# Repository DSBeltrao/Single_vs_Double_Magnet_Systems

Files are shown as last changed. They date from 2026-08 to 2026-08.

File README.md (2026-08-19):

This repository supports the paper "Actuation Comparison of Microrobots Using Single and Double Permanent Magnets." It contains all files needed to reproduce the simulations, the experimental setup, calculations and 3D prints.

Repository Structure

1. **Simulations** – Source files for simulating the magnetic field generation, gradient velocity and navigation control.
2. **Experimental Setup** – Wiring diagram, manuals for the electronic components, Arduino codes, Python codes, list of setup parts and overview of control procedure.
3. **Experimental Calculations** - Python codes for extracting and processing data.
4. **3D Prints** - Files containing the 3D prints used for the system setup in the formats 3mf and f3d.

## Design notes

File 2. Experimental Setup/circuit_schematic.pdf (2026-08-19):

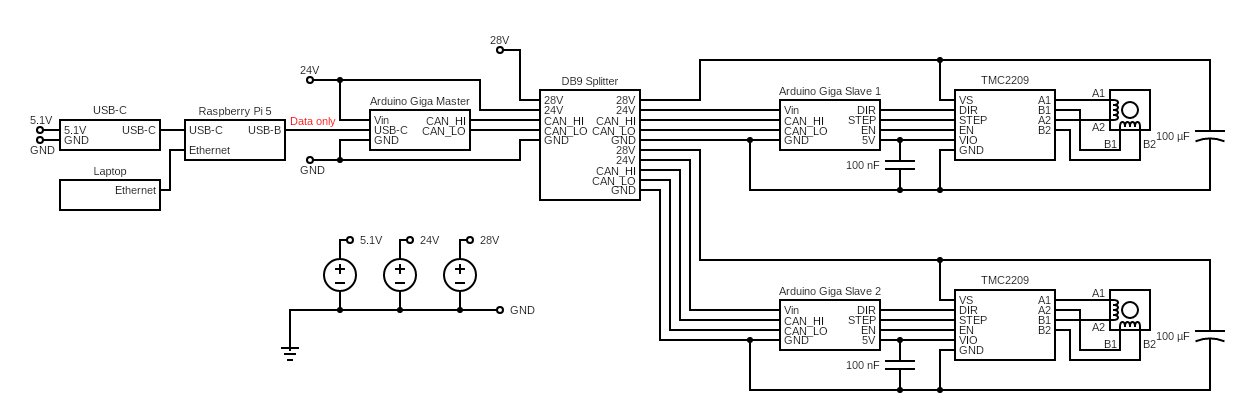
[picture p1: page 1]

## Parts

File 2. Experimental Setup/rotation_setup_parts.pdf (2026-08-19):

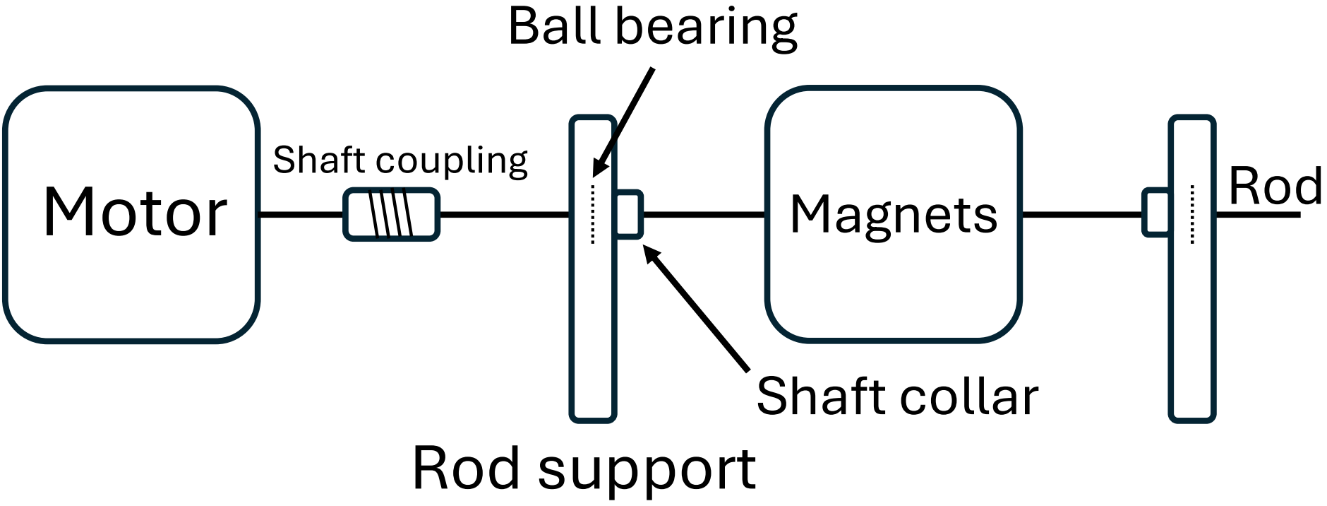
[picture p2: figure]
Motor; Shaft coupling; Rod support; Shaft collar; Magnets; Ball bearing; Rod

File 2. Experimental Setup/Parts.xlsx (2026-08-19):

Component | Quantity
Structure
Aluminium profile 8 500x40x40 mm | 14
Aluminium profile 8 500x80x40 mm | 4
Cube fastening 3D profile 8 | 8
Automatic fastening screws profile 8 | 24
Acryllic plates
Acryllic protection plate 520x520x2 mm | 5
Acryllic pool support plate 500x580x4 mm | 1
Acryllic pool plate stroke 500x20x4 mm | 2
Electonics
NEMA 17 stepper motor | 2
TMC2209 stepper driver | 2
Arduino GIGA R1 | 3
Arduino GIGA CAN hat | 2
Raspberry Pi 5 8GB and accesoires (SD card, power, casing, etc.) | 1
DB9 cable | 2
DB9 splitter | 1
100uF capacitor | 2
100nF capacitor | 2
EDU36311A Triple Output Programmable Power Supply | 1
USB-B to USB-C data only cable | 1
USB-C open end cable | 1
Ethernet cable | 1
3D prints and accessories
Magnet holder | 2
Rod support | 2
Arduino mount | 2
Acryllic plate holder | 10
Motor mount | 2
Pool | 1
Profile 8 M4 15 mm screw and nut | 20
M3 6 mm screw | 8
M3 10 mm screw | 16
M2 20 mm grub screw | 8
Steel rod 5mm diameter 250 mm length | 2
Shaft collar 5 mm | 4
Ball bearing 5x16x5 mm | 4
Hot melt insert M2 | 8
Hot melt insert M3 | 16
M3 nut | 8
Flexible shaft coupling 5mm-5mm | 2
Magnet 40x40x20 N42 | 4
Microrobot | 1
Glycerin
15x15 cm printed grid | 1

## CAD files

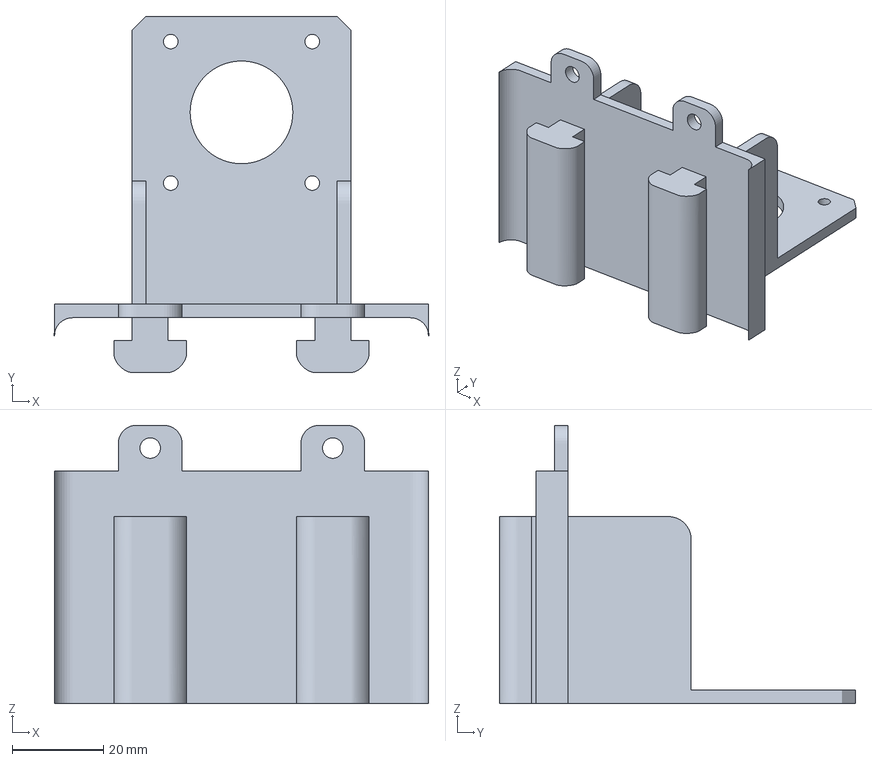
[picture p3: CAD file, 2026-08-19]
4. 3D Prints/3mf_files/motorMount.3mf
82.0 x 78.0 x 61.0 mm

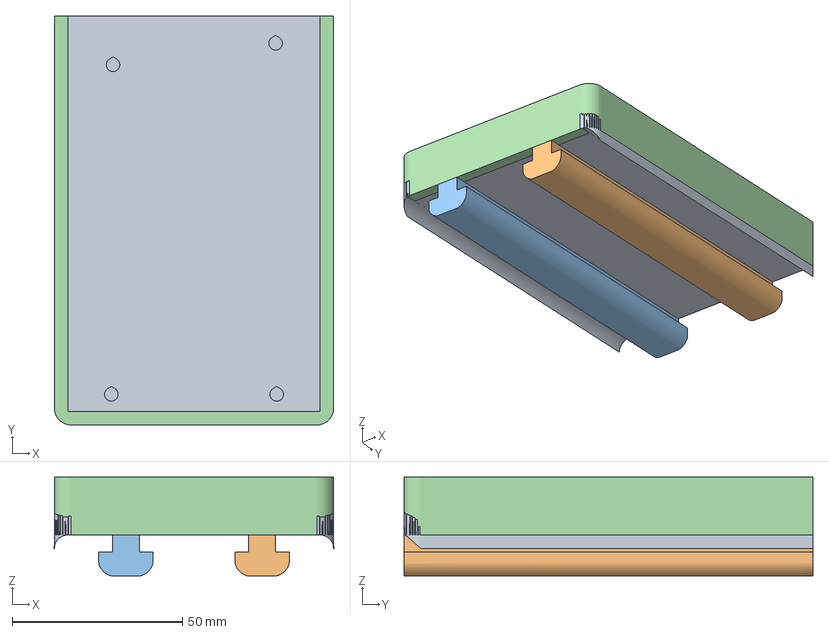
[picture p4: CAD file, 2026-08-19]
4. 3D Prints/3mf_files/arduinoMount.3mf
82.0 x 120.0 x 29.0 mm

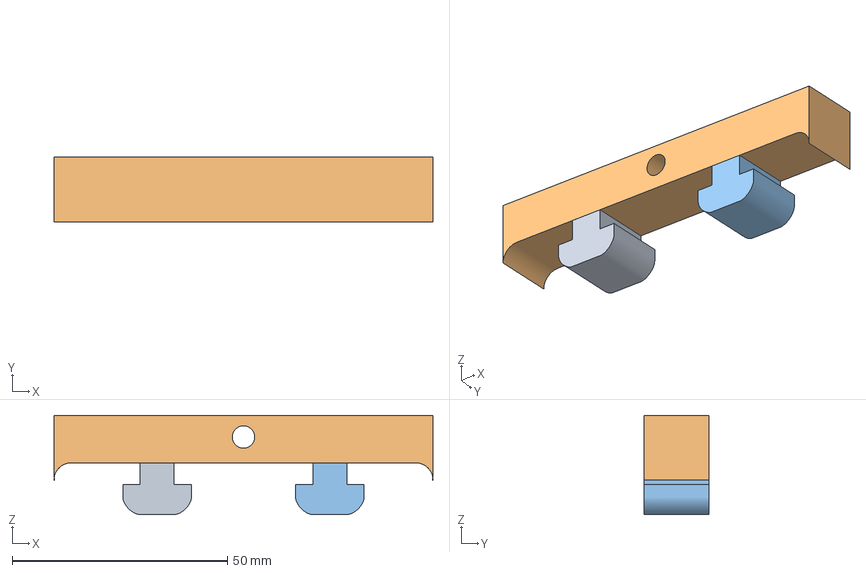
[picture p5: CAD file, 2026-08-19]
4. 3D Prints/3mf_files/dimensionsTest.3mf
88.0 x 15.0 x 23.0 mm

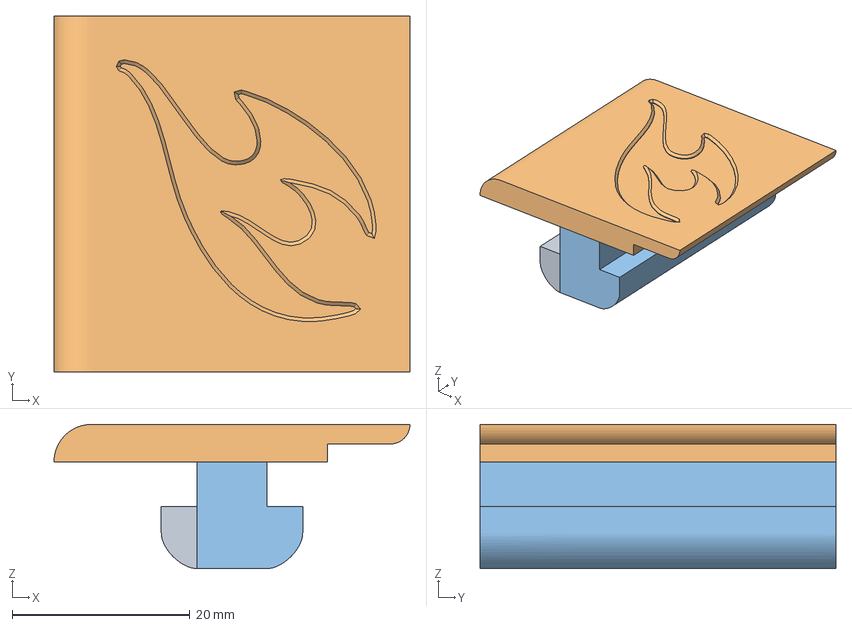
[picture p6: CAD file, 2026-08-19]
4. 3D Prints/3mf_files/pmmaClip.3mf
40.0 x 40.0 x 16.2 mm

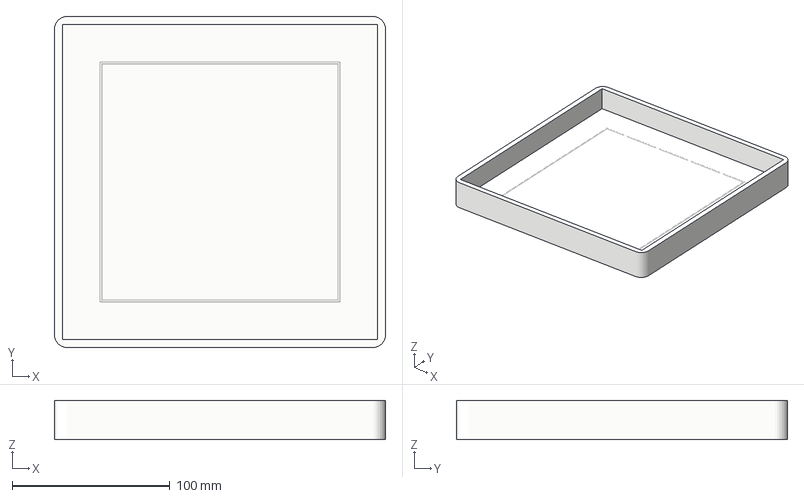
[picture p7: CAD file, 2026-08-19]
4. 3D Prints/3mf_files/Pool.3mf
210.0 x 210.0 x 25.0 mm

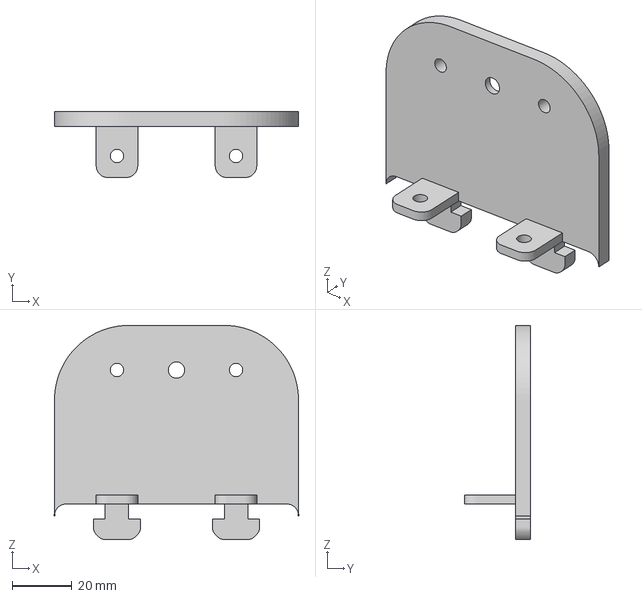
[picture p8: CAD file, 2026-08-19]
4. 3D Prints/3mf_files/rodSupport.3mf
82.0 x 22.2 x 72.0 mm

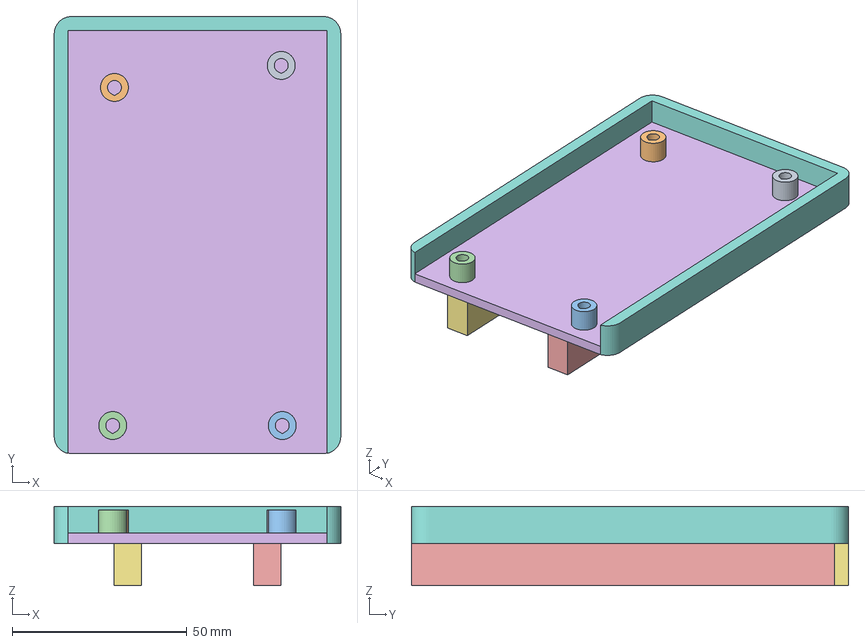
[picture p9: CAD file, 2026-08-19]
4. 3D Prints/3mf_files/arduinoMount4080.3mf
82.0 x 125.0 x 22.7 mm

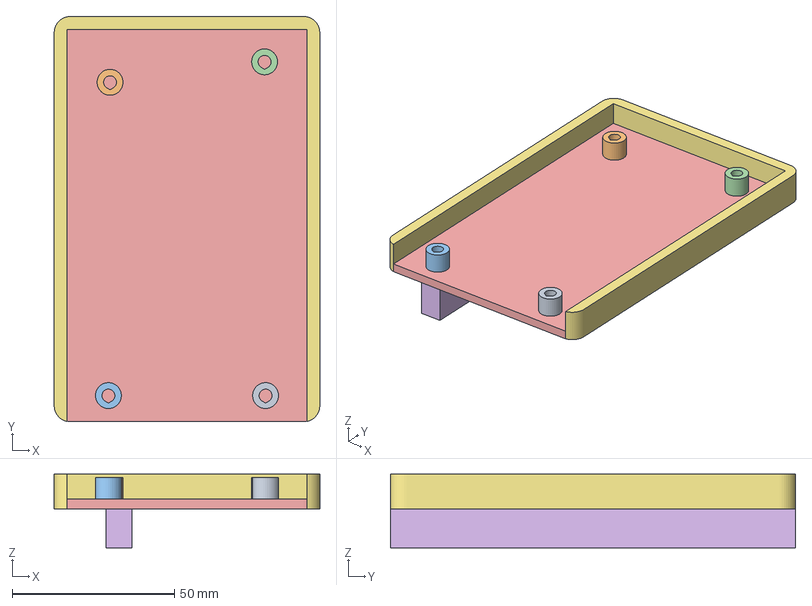
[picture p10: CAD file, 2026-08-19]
4. 3D Prints/3mf_files/arduinoMount4040.3mf
82.0 x 125.0 x 22.7 mm

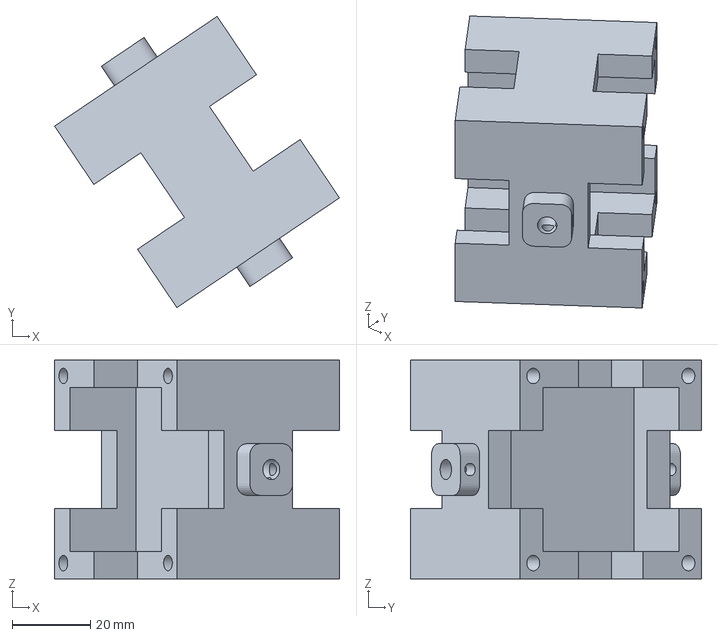
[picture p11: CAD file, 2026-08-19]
4. 3D Prints/3mf_files/cubeHolder.3mf
72.9 x 74.5 x 56.0 mm

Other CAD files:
4. 3D Prints/f3d_files/Pool.f3d
4. 3D Prints/f3d_files/arduinoMount4040.f3d
4. 3D Prints/f3d_files/arduinoMount4080.f3d
4. 3D Prints/f3d_files/cubeHolder.f3d
4. 3D Prints/f3d_files/cubeHolderCap.f3d
4. 3D Prints/f3d_files/dimensionsTest.f3d
4. 3D Prints/f3d_files/motorMount.f3d
4. 3D Prints/f3d_files/pmmaClip.f3d
4. 3D Prints/f3d_files/rodSupport.f3d

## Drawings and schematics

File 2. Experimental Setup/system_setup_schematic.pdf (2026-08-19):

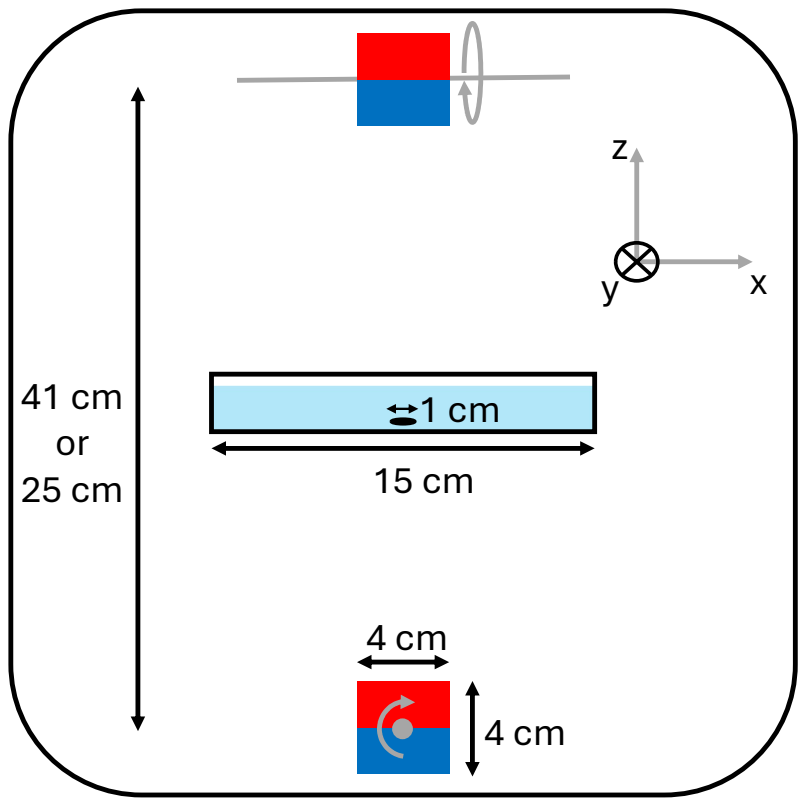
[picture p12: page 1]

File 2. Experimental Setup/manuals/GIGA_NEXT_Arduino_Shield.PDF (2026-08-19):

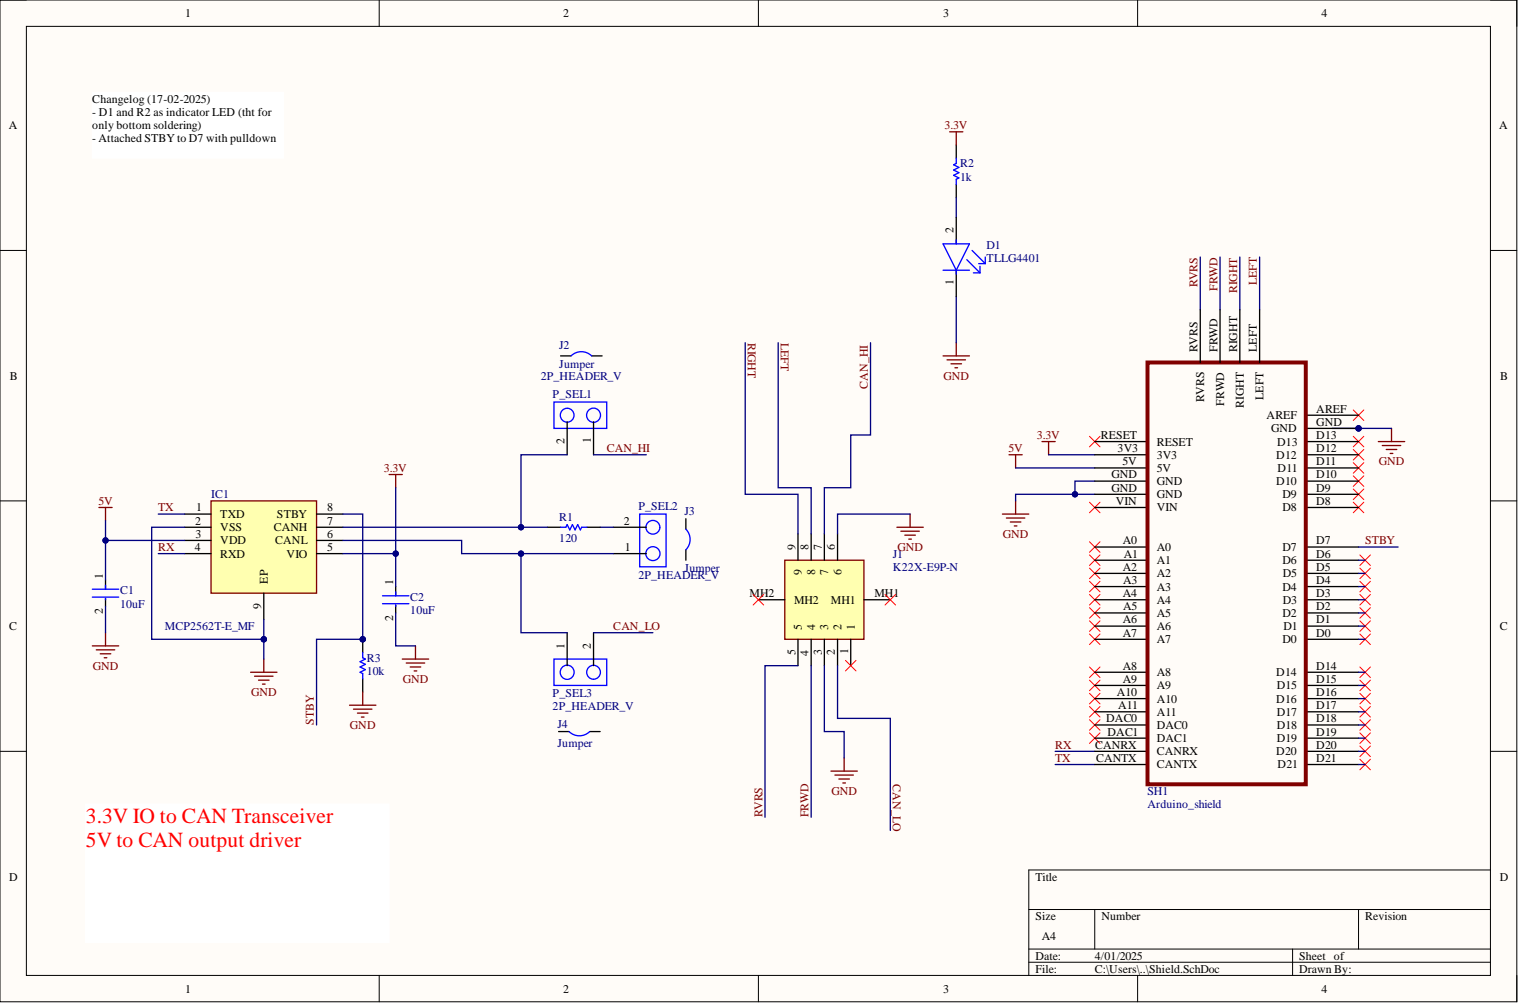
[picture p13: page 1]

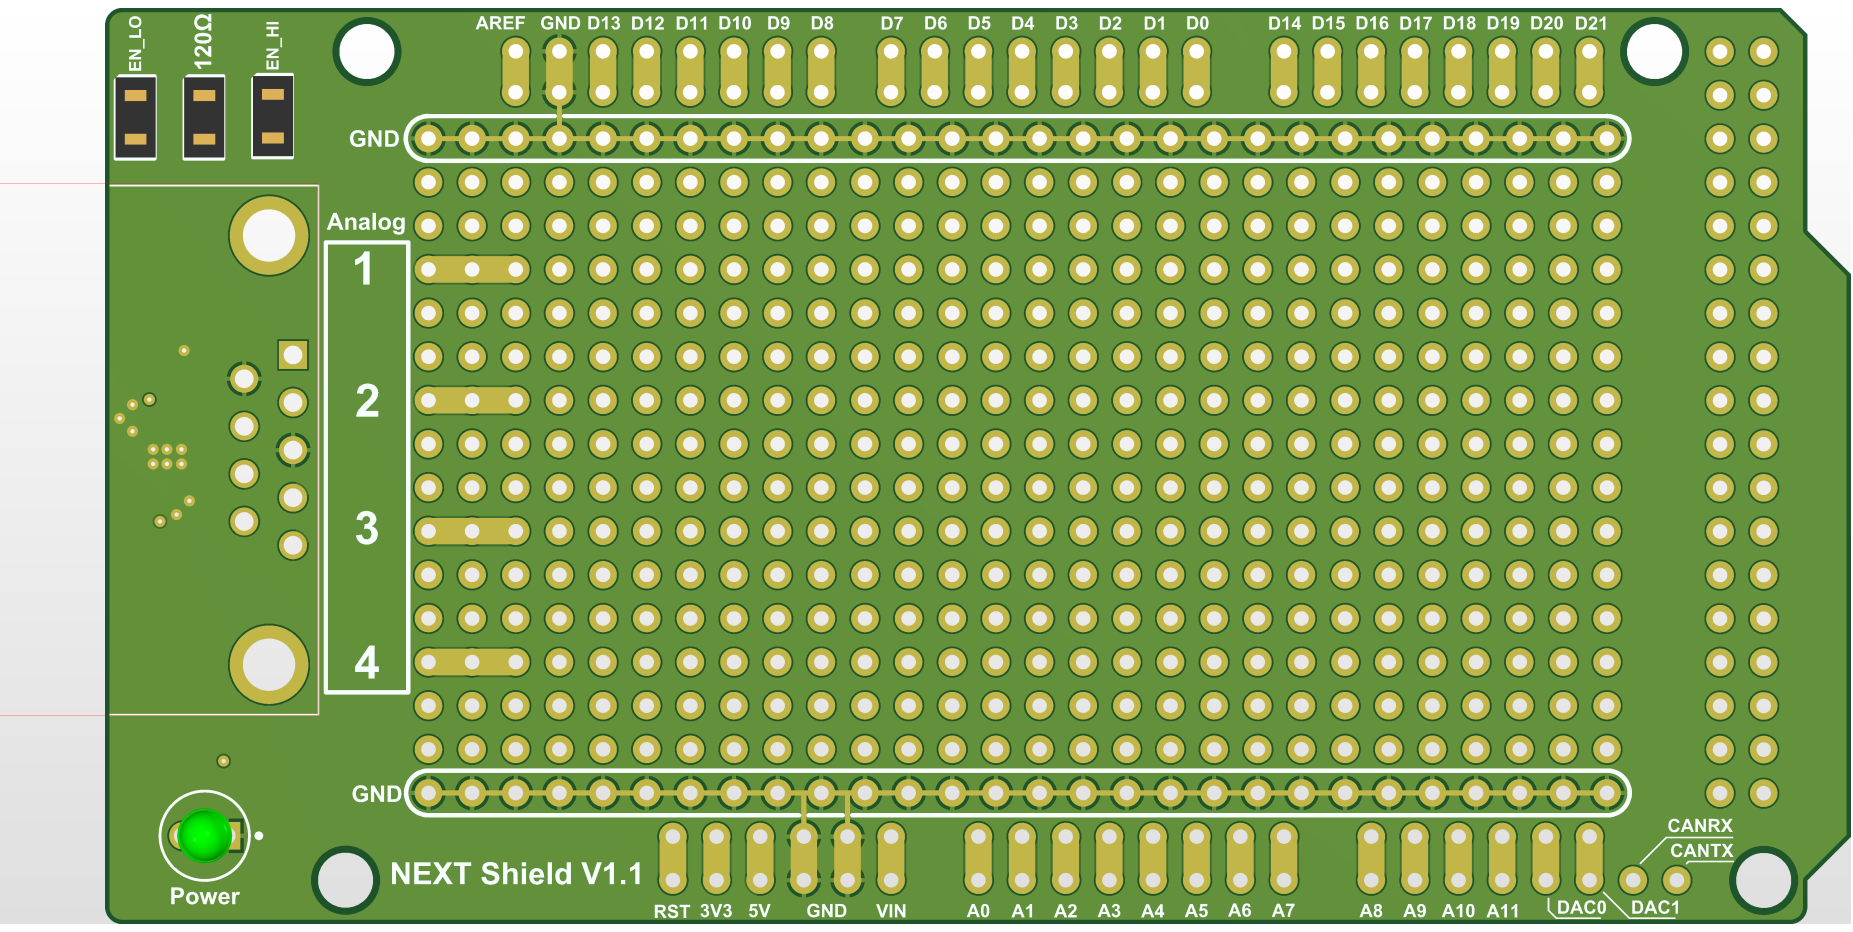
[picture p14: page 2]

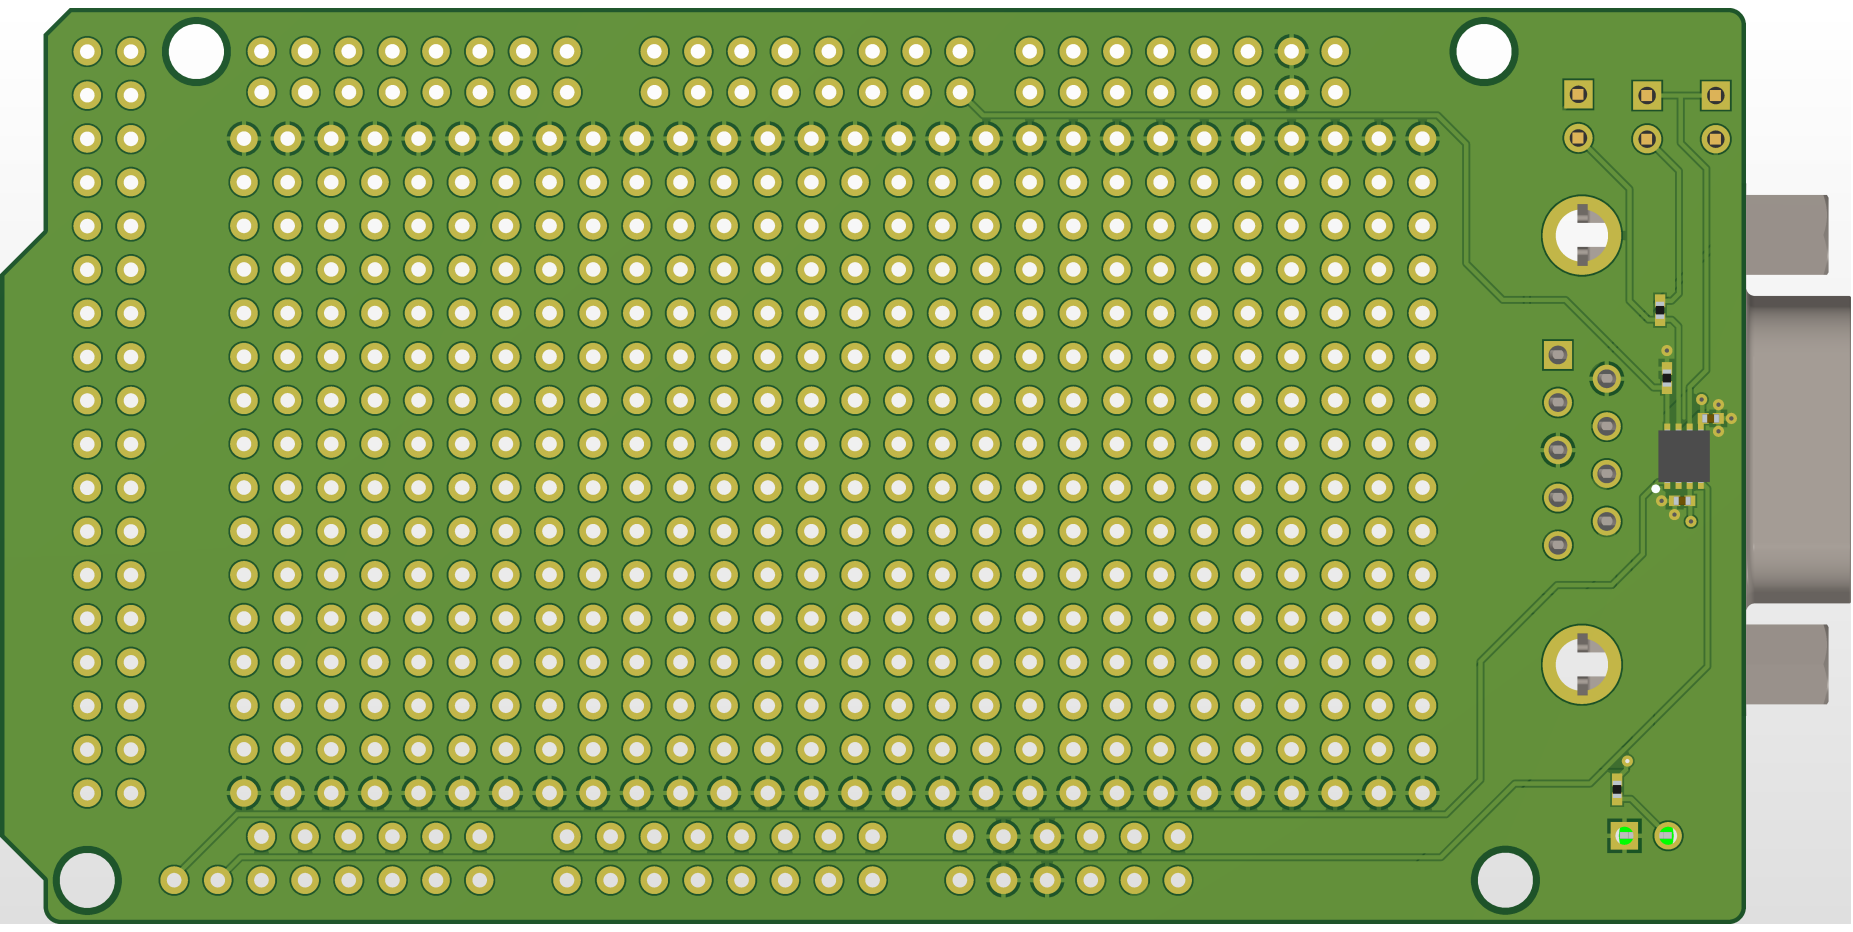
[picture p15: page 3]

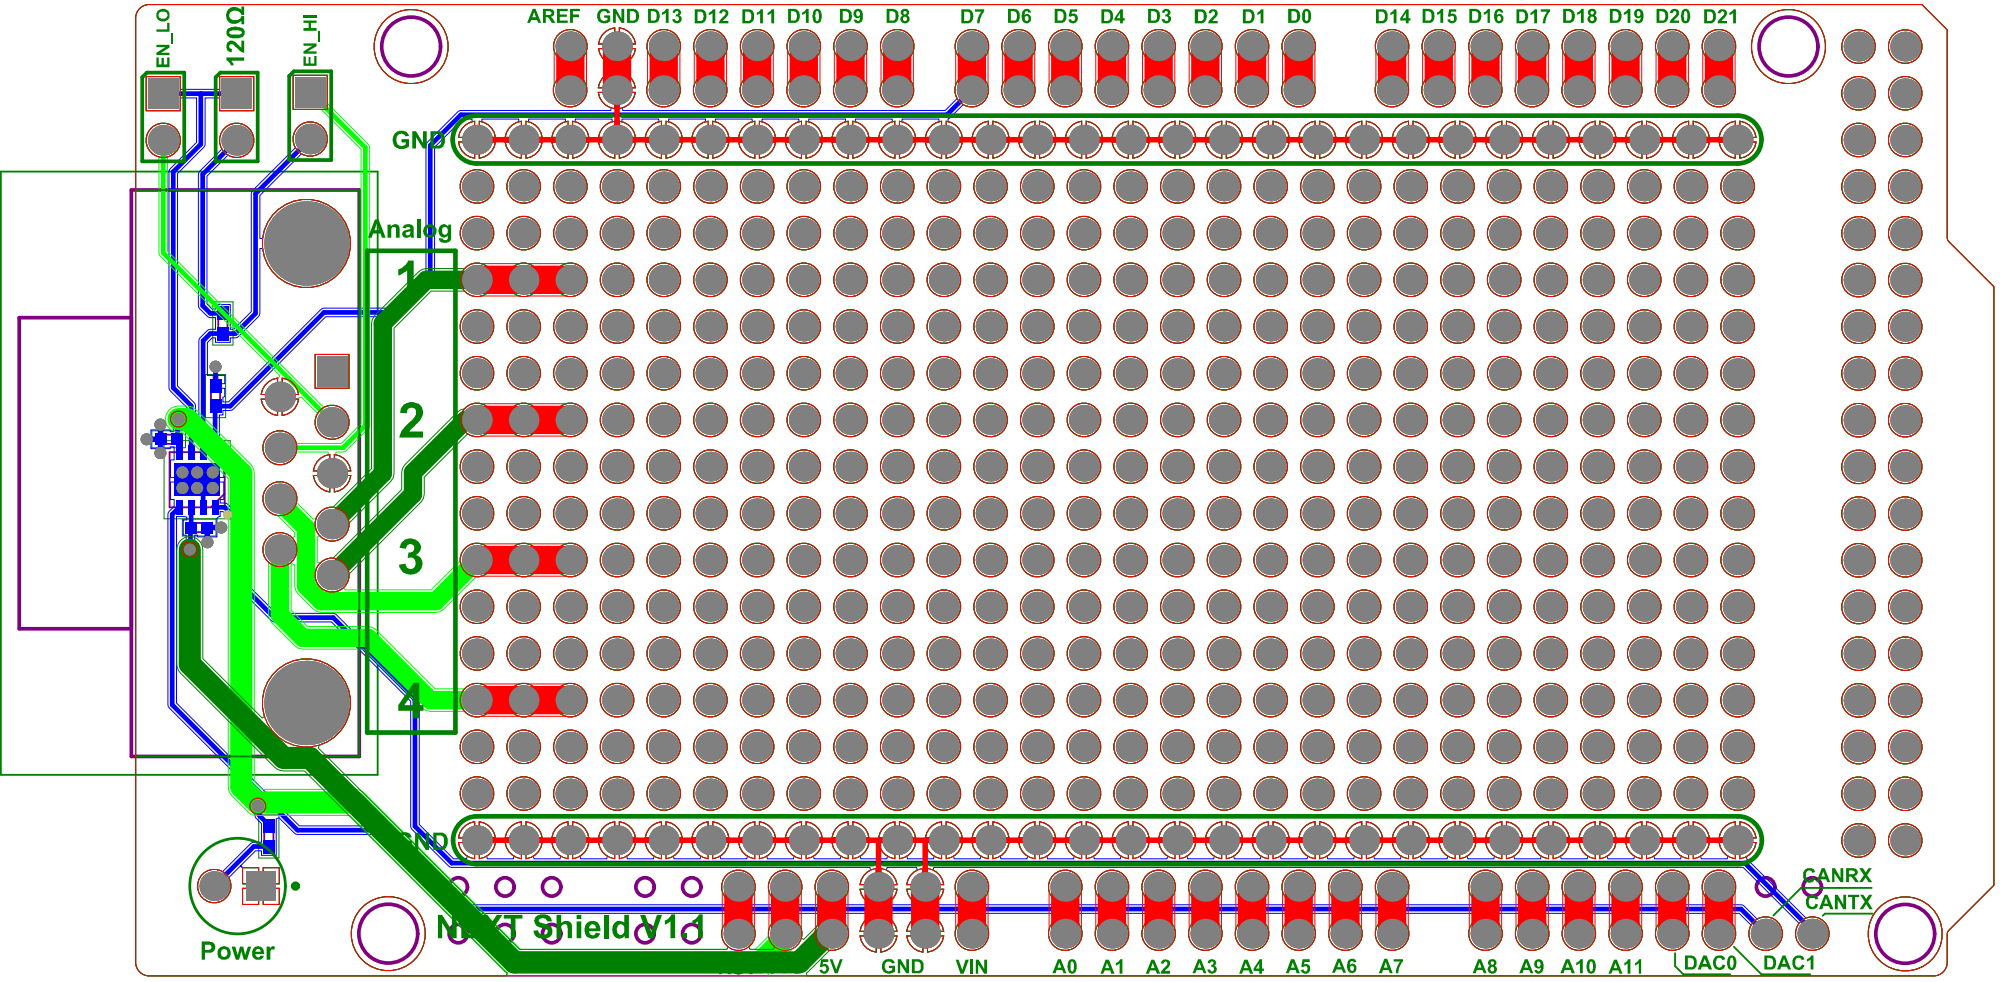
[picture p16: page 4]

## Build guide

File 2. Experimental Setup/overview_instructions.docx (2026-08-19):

This file contains an overview of the important parts for the experimentation setup. It describes the necessary setup for the stepper motor, driver, Arduino and Pi and the procedure to control the setup. Pi information: https://www.raspberrypi.com/documentation/

- Hostname/username: microrobotpi
- Password: I<3microrobots
- Wifi: eduroam
- Password: tudmfmrs
- IP: 192.168.1.2

Arduino: https://docs.arduino.cc/hardware/giga-r1-wifi/

TMC2209: https://www.scribd.com/document/890126314/BIGTREETECH

# Wiring

Important to follow the wiring described in the circuit_schematic.pdf, including the capacitors for electronics protection. For powering the system, the following measures were taken:

- Arduino 24V
- Raspberry Pi 5.1V
- NEMA17 28V
- Everything connected to the same ground
- On the Keysight, all channel grounds are connected to the earth terminal
- TMC2209 were referenced at 0.3V

# Control procedure

- Connect the laptop to the Pi (ethernet), the Pi to the master Arduino (USB-B to USB-C) and the master Arduino to the slave Arduinos (DB9+splitter)
- Power the Arduinos and Pi
- Connect only one motor to the TMC2209 and turn motor power on on the Keysight
- Wait a few seconds until connecting the second motor to the second TMC2209 (make sure the power channel for the motors stays in CV mode)
- Open the Terminal on the laptop (cmd in “Search”)
- Start the ssh connection inserting: ssh microrobotpi@microrobotpi.local
- If that does not work, try: ssh microrobotpi@192.168.12
- If that does not work, check if the connection is right
- Insert password (it will not be visible): I<3microrobots
- A connection will be established. To ensure connection, type ls to see the files on the Pi
- After uploading the four files in the folder “2. Experimental Setup/pi”, run server.py: python server.py
- On the laptop, open client_pi_path.py, insert the desired parameters and run it

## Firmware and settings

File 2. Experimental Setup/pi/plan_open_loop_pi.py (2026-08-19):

"""
plan_open_loop_pi.py

Pi-facing wrapper around your geometry + inverse solver + open-loop planner.

What it does
------------
1. Receives waypoint-based path requests from the socket server.
2. Runs a sequential open-loop planner.
3. Writes:
   - full command CSV
   - motor-only CSV
   - motor-only JSON

Optional:
- stop-and-align at segment corners by inserting fixed-position alignment rows
  before propulsion continues on the next segment.
"""

from __future__ import annotations

import csv
import json
from pathlib import Path

import numpy as np

from planner_geometry import PathGeometry
from field_inverse_solver import FieldInverseSolver


def desired_field_direction(N_hat: np.ndarray, B_hat: np.ndarray, phi_rad: float) -> np.ndarray:
    return np.cos(phi_rad) * N_hat + np.sin(phi_rad) * B_hat


def write_csv(rows: list[dict], path: str | Path) -> None:
    if not rows:
        return
    path = Path(path)
    path.parent.mkdir(parents=True, exist_ok=True)

    with path.open("w", newline="") as f:
        writer = csv.DictWriter(f, fieldnames=list(rows[0].keys()))
        writer.writeheader()
        writer.writerows(rows)


def write_json(obj, path: str | Path) -> None:
    path = Path(path)
    path.parent.mkdir(parents=True, exist_ok=True)
    with path.open("w", encoding="utf-8") as f:
        json.dump(obj, f, indent=2)


def extract_motor_rows(commands: list[dict]) -> list[dict]:
    motor_rows = []
    for row in commands:
        motor_rows.append(
            {
                "k": int(row["k"]),
                "t_s": float(row["t_s"]),
                "theta_x_deg": float(row["theta_x_deg"]),
                "theta_y_deg": float(row["theta_y_deg"]),
            }
        )
    return motor_rows


def solve_align_hold_sequence(
    geometry: PathGeometry,
    solver: FieldInverseSolver,
    seg_idx_next: int,
    pos_cm: np.ndarray,
    t_start_s: float,
    k_start: int,
    prev_angles_deg: tuple[float, float] | None,
    align_steps: int,
) -> tuple[list[dict], tuple[float, float] | None]:
    """
    Insert fixed-position alignment commands before starting the new segment.

    The target alignment vector is the in-plane perpendicular to the new segment
    tangent, i.e. the planar Bishop normal N_hat of that next segment.
    """
    if align_steps <= 0:
        return [], prev_angles_deg

    T_next = geometry.T_segs[seg_idx_next].copy()
    N_next = geometry.N_segs[seg_idx_next].copy()
    B_next = geometry.B_segs[seg_idx_next].copy()

    result = solver.solve_step(
        pos_cm=(float(pos_cm[0]), float(pos_cm[1])),
        desired_dir=N_next,
        N_hat=N_next,
        B_hat=B_next,
        prev_angles_deg=prev_angles_deg,
    )
    chosen = solver.pick_best_solution(result["solutions"], prev_angles_deg)
    if chosen is None:
        return [], prev_angles_deg

    theta_target_x = float(chosen["theta_x_deg"])
    theta_target_y = float(chosen["theta_y_deg"])
    Bmag_mT = float(chosen["Bmag_mT"])
    align_cos = float(chosen["align_cos"])

    rows = []

    if prev_angles_deg is None:
        tx0, ty0 = theta_target_x, theta_target_y
    else:
        tx0, ty0 = prev_angles_deg

    for j, a in enumerate(np.linspace(0.0, 1.0, align_steps, endpoint=True)):
        tx = (1.0 - a) * tx0 + a * theta_target_x
        ty = (1.0 - a) * ty0 + a * theta_target_y

        rows.append(
            {
                "k": k_start + j,
                "t_s": float(t_start_s + j * 0.0),  # overwritten by caller if wanted
                "mode": "align",
                "seg_idx": int(seg_idx_next),
                "s_ideal_cm": None,
                "s_pred_cm": None,
                "x_pred_cm": float(pos_cm[0]),
                "y_pred_cm": float(pos_cm[1]),
                "phi_cmd_deg": None,
                "phi_used_deg": None,
                "phase_steps": int(result["phase_steps"]) if result["phase_steps"] is not None else None,
                "Bdes_x": float(N_next[0]),
                "Bdes_y": float(N_next[1]),
                "Bdes_z": float(N_next[2]),
                "Bused_x": float(result["desired_used_hat"][0]),
                "Bused_y": float(result["desired_used_hat"][1]),
                "Bused_z": float(result["desired_used_hat"][2]),
                "theta_x_deg": float(tx),
                "theta_y_deg": float(ty),
                "Bmag_mT": Bmag_mT,
                "align_cos": align_cos,
                "speed_scale": 0.0,
                "ds_nominal_cm": 0.0,
                "ds_pred_cm": 0.0,
            }
        )

    return rows, (theta_target_x, theta_target_y)


def plan_open_loop_pi(
    waypoints_cm,
    s_start_cm: float = 0.0,
    phi_start_deg: float = 0.0,
    command_rate_hz: float = 20.0,
    rotation_freq_hz: float = 1.0,
    pitch_cm_per_rot: float = 0.124,
    max_time_s: float = 120.0,
    pool_size_cm: float = 15.0,
    align_steps_per_corner: int = 0,
) -> list[dict]:
    geometry = PathGeometry(waypoints_cm, pool_size_cm=pool_size_cm)

    solver = FieldInverseSolver(
        pool_size_cm=pool_size_cm,
        magnet_offset_z_cm=20.5,
        dipole_moment_Am2=66.0,
        cone_default_deg=5.0,
        cone_max_deg=12.0,
        dphi_deg=20.0,
        phase_sign=-1.0,
        B_expand_mT=6.0,
        B_sync_mT=4.0,
        B_min_mT=0.5,
        local_span_deg=30.0,
        local_step_deg=15.0,
        global_seeds_deg=(0.0, 90.0, 180.0, 270.0),
        w_angle=1.0,
        w_mag=2.0,
        w_align=0.05,
    )

    dt_s = 1.0 / float(command_rate_hz)
    delta_phi_rad = 2.0 * np.pi * float(rotation_freq_hz) * dt_s
    max_steps = int(float(max_time_s) * float(command_rate_hz))
    ds_nominal_cm = float(pitch_cm_per_rot) * (delta_phi_rad / (2.0 * np.pi))

    s_pred_cm = float(s_start_cm)
    s_ideal_cm = float(s_start_cm)
    phi_rad = np.deg2rad(phi_start_deg)

    prev_angles_deg = None
    commands: list[dict] = []

    prev_seg_idx = None
    k_out = 0

    for _ in range(max_steps):
        if s_pred_cm >= geometry.total_length_cm:
            break

        q = geometry.query(s_pred_cm)
        pos_cm = q["pos_cm"]
        seg_idx = int(q["seg_idx"])
        N_hat = q["N_hat"]
        B_hat = q["B_hat"]

        # Optional stop-and-align when entering a new segment.
        if (
            align_steps_per_corner > 0
            and prev_seg_idx is not None
            and seg_idx != prev_seg_idx
        ):
            align_rows, prev_angles_deg = solve_align_hold_sequence(
                geometry=geometry,
                solver=solver,
                seg_idx_next=seg_idx,
                pos_cm=pos_cm,
                t_start_s=k_out * dt_s,
                k_start=k_out,
                prev_angles_deg=prev_angles_deg,
                align_steps=align_steps_per_corner,
            )

            for j, row in enumerate(align_rows):
                row["t_s"] = (k_out + j) * dt_s

            commands.extend(align_rows)
            k_out += len(align_rows)

        B_des_hat = desired_field_direction(N_hat, B_hat, phi_rad)

        result = solver.solve_step(
            pos_cm=(float(pos_cm[0]), float(pos_cm[1])),
            desired_dir=B_des_hat,
            N_hat=N_hat,
            B_hat=B_hat,
            prev_angles_deg=prev_angles_deg,
        )

        chosen = solver.pick_best_solution(result["solutions"], prev_angles_deg)
        if chosen is None:
            break

        theta_x_deg = float(chosen["theta_x_deg"])
        theta_y_deg = float(chosen["theta_y_deg"])
        Bmag_mT = float(chosen["Bmag_mT"])
        align_cos = float(chosen["align_cos"])

        speed_scale = float(solver.speed_scale_from_B(Bmag_mT))
        ds_pred_cm = ds_nominal_cm * speed_scale

        phi_used_rad = result["phi_used_rad"]
        phi_next_rad = phi_used_rad + solver.phase_sign * delta_phi_rad

        commands.append(
            {
                "k": k_out,
                "t_s": k_out * dt_s,
                "mode": "propel",
                "seg_idx": seg_idx,
                "s_ideal_cm": float(s_ideal_cm),
                "s_pred_cm": float(s_pred_cm),
                "x_pred_cm": float(pos_cm[0]),
                "y_pred_cm": float(pos_cm[1]),
                "phi_cmd_deg": float(np.rad2deg(phi_rad) % 360.0),
                "phi_used_deg": float(np.rad2deg(phi_used_rad) % 360.0),
                "phase_steps": int(result["phase_steps"]) if result["phase_steps"] is not None else None,
                "Bdes_x": float(B_des_hat[0]),
                "Bdes_y": float(B_des_hat[1]),
                "Bdes_z": float(B_des_hat[2]),
                "Bused_x": float(result["desired_used_hat"][0]),
                "Bused_y": float(result["desired_used_hat"][1]),
                "Bused_z": float(result["desired_used_hat"][2]),
                "theta_x_deg": theta_x_deg,
                "theta_y_deg": theta_y_deg,
                "Bmag_mT": Bmag_mT,
                "align_cos": align_cos,
                "speed_scale": speed_scale,
                "ds_nominal_cm": float(ds_nominal_cm),
                "ds_pred_cm": float(ds_pred_cm),
            }
        )

        prev_angles_deg = (theta_x_deg, theta_y_deg)
        prev_seg_idx = seg_idx
        s_ideal_cm += ds_nominal_cm
        s_pred_cm += ds_pred_cm
        phi_rad = phi_next_rad
        k_out += 1

    return commands


def plan_from_request(request: dict) -> dict:
    waypoints_cm = request["waypoints_cm"]

    s_start_cm = float(request.get("s_start_cm", 0.0))
    phi_start_deg = float(request.get("phi_start_deg", 0.0))
    command_rate_hz = float(request.get("command_rate_hz", 20.0))
    rotation_freq_hz = float(request.get("rotation_freq_hz", 1.0))
    pitch_cm_per_rot = float(request.get("pitch_cm_per_rot", 0.124))
    max_time_s = float(request.get("max_time_s", 120.0))
    pool_size_cm = float(request.get("pool_size_cm", 15.0))
    align_steps_per_corner = int(request.get("align_steps_per_corner", 0))

    output_dir = Path(request.get("output_dir", "."))
    base_name = str(request.get("base_name", "latest"))
    write_full_commands = bool(request.get("write_full_commands", True))
    write_motor_only = bool(request.get("write_motor_only", True))

    commands = plan_open_loop_pi(
        waypoints_cm=waypoints_cm,
        s_start_cm=s_start_cm,
        phi_start_deg=phi_start_deg,
        command_rate_hz=command_rate_hz,
        rotation_freq_hz=rotation_freq_hz,
        pitch_cm_per_rot=pitch_cm_per_rot,
        max_time_s=max_time_s,
        pool_size_cm=pool_size_cm,
        align_steps_per_corner=align_steps_per_corner,
    )

    output_dir.mkdir(parents=True, exist_ok=True)

    full_csv = output_dir / f"{base_name}_commands_open_loop.csv"
    motor_csv = output_dir / f"{base_name}_motor_angles.csv"
    motor_json = output_dir / f"{base_name}_motor_angles.json"

    if write_full_commands:
        write_csv(commands, full_csv)

    motor_rows = extract_motor_rows(commands)

    if write_motor_only:
        write_csv(motor_rows, motor_csv)
        write_json(motor_rows, motor_json)

    first_angles_deg = None
    last_angles_deg = None
    if motor_rows:
        first_angles_deg = [motor_rows[0]["theta_x_deg"], motor_rows[0]["theta_y_deg"]]
        last_angles_deg = [motor_rows[-1]["theta_x_deg"], motor_rows[-1]["theta_y_deg"]]

    return {
        "num_commands": len(commands),
        "num_motor_rows": len(motor_rows),
        "full_csv": str(full_csv),
        "motor_csv": str(motor_csv),
        "motor_json": str(motor_json),
        "first_angles_deg": first_angles_deg,
        "last_angles_deg": last_angles_deg,
    }


if __name__ == "__main__":
    request = {
        "waypoints_cm": [
            [7.5, 7.5],
            [1, 7.5],
        ],
        "s_start_cm": 0.0,
        "phi_start_deg": 0.0,
        "command_rate_hz": 20.0,
        "rotation_freq_hz": 1.0,
        "pitch_cm_per_rot": 0.124,
        "max_time_s": 120.0,
        "pool_size_cm": 15.0,
        "output_dir": ".",
        "base_name": "latest",
        "write_full_commands": True,
        "write_motor_only": True,
        "align_steps_per_corner": 0,
    }

    result = plan_from_request(request)
    print(json.dumps(result, indent=2))

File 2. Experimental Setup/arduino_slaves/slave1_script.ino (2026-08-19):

#include <Arduino_CAN.h>
#include <AccelStepper.h>
#include <math.h>

#define SLAVE_INDEX 1   // 1 for slave 1, 2 for slave 2

#define DIR_PIN 2
#define STEP_PIN 3
#define ENABLE_PIN 4
#define CAN_STBY_PIN 7

AccelStepper stepper(AccelStepper::DRIVER, STEP_PIN, DIR_PIN);

static uint32_t const ID_CMD_BROADCAST = 0x100;

const long STEPS_PER_REV = 1600;   // 1/8 microstep
const int DIR_SIGN = -1;

float MAX_SPEED_STEPS = 8000.0f;
float ACCEL_STEPS     = 15000.0f;

long degToSteps(float deg) {
  return lround((deg / 360.0f) * STEPS_PER_REV) * DIR_SIGN;
}

float stepsToDegUnwrapped(long steps) {
  return (360.0f * steps / STEPS_PER_REV) * DIR_SIGN;
}

float wrap360(float deg) {
  while (deg >= 360.0f) deg -= 360.0f;
  while (deg < 0.0f) deg += 360.0f;
  return deg;
}

float wrap180(float deg) {
  while (deg >= 180.0f) deg -= 360.0f;
  while (deg < -180.0f) deg += 360.0f;
  return deg;
}

float currentClockDeg() {
  return wrap360(stepsToDegUnwrapped(stepper.currentPosition()));
}

float uint16x10ToDeg(uint16_t v) {
  return ((float)v) / 10.0f;
}

void commandClockAngle(float cmdClockDeg) {
  float currClockDeg = currentClockDeg();
  float deltaDeg = wrap180(cmdClockDeg - currClockDeg);
  long deltaSteps = degToSteps(deltaDeg);
  long targetSteps = stepper.currentPosition() + deltaSteps;

  stepper.moveTo(targetSteps);

  Serial.print("EXEC_CMD,cmd=");
  Serial.print(cmdClockDeg, 4);
  Serial.print(",curr=");
  Serial.print(currClockDeg, 4);
  Serial.print(",delta=");
  Serial.print(deltaDeg, 4);
  Serial.print(",target_clock=");
  Serial.print(wrap360(currClockDeg + deltaDeg), 4);
  Serial.print(",target_steps=");
  Serial.println(targetSteps);
}

void handleLocalSerial(String line) {
  line.trim();
  if (line.length() == 0) return;

  if (line == "PING") {
    Serial.println("PONG");
    return;
  }

  if (line == "ZERO") {
    stepper.setCurrentPosition(0);
    Serial.println("ZERO_OK");
    return;
  }

  if (line == "POS?") {
    Serial.print("POS_CLOCK_DEG,");
    Serial.println(currentClockDeg(), 4);
    return;
  }

  if (line.startsWith("SPEED,")) {
    float v = line.substring(6).toFloat();
    if (v > 0.0f) {
      MAX_SPEED_STEPS = v;
      stepper.setMaxSpeed(MAX_SPEED_STEPS);
      Serial.print("SPEED_OK,");
      Serial.println(MAX_SPEED_STEPS, 2);
    } else {
      Serial.println("ERR_BAD_SPEED");
    }
    return;
  }

  if (line.startsWith("ACCEL,")) {
    float a = line.substring(6).toFloat();
    if (a > 0.0f) {
      ACCEL_STEPS = a;
      stepper.setAcceleration(ACCEL_STEPS);
      Serial.print("ACCEL_OK,");
      Serial.println(ACCEL_STEPS, 2);
    } else {
      Serial.println("ERR_BAD_ACCEL");
    }
    return;
  }

  Serial.print("ERR_UNKNOWN,");
  Serial.println(line);
}

void setup() {
  pinMode(ENABLE_PIN, OUTPUT);
  digitalWrite(ENABLE_PIN, LOW);

  Serial.begin(115200);
  //while (!Serial) {}

  pinMode(CAN_STBY_PIN, OUTPUT);
  digitalWrite(CAN_STBY_PIN, LOW);

  if (!CAN.begin(CanBitRate::BR_500k)) {
    //Serial.println("CAN.begin failed");
    while (1) {}
  }

  stepper.setMaxSpeed(MAX_SPEED_STEPS);
  stepper.setAcceleration(ACCEL_STEPS);
  stepper.setCurrentPosition(0);

  Serial.print("SLAVE_READY,index=");
  Serial.println(SLAVE_INDEX);
  Serial.println("ZERO_IS_PLUS_Z");
  Serial.print("STEPS_PER_REV,");
  Serial.println(STEPS_PER_REV);
}

void loop() {
  if (Serial.available()) {
    String line = Serial.readStringUntil('\n');
    handleLocalSerial(line);
  }

  if (CAN.available()) {
    CanMsg const msg = CAN.read();

    if (msg.id == CanStandardId(ID_CMD_BROADCAST) && msg.data_length >= 6) {
      uint16_t k  = (uint16_t(msg.data[0]) << 8) | msg.data[1];

      if (k == 0xFFFF) {
        Serial.println("RETURN_TO_ZERO");
        commandClockAngle(0.0f);
      } else {
        uint16_t a1 = (uint16_t(msg.data[2]) << 8) | msg.data[3];
        uint16_t a2 = (uint16_t(msg.data[4]) << 8) | msg.data[5];

        float myDeg = (SLAVE_INDEX == 1) ? uint16x10ToDeg(a1)
                                         : uint16x10ToDeg(a2);

        Serial.print("RX_CMD,k=");
        Serial.print(k);
        Serial.print(",my_deg=");
        Serial.println(myDeg, 4);

        commandClockAngle(myDeg);
      }
    }
  }

  stepper.run();
}
